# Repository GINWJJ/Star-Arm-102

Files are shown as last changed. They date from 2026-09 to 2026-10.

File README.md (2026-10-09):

<h1 align="center">🦾 Star Arm 102</h1>

<p align="center">
  <strong>Open-Source 6+1 DOF Robot Arm for LeRobot</strong><br>
  Teleoperate. Learn from demonstrations. Run your first AI task.
</p>

<p align="center">
  
  
  
  
  
</p>

<p align="center">
  
  
</p>

<p align="center">
  <a href="https://fashionstar.com.hk/">🌐 Official Website</a> ·
  <a href="https://fashionstar.com.hk/robot-arm/star-arm-102">🔭 Series Overview</a> ·
  <a href="#where-to-buy">🛒 Where to Buy</a> ·
  <a href="https://fashionstar.com.hk/support/">💬 Support</a>
</p>

<p align="center">
  <a href="https://fashionstar.com.hk/store/collections/robot-arm/star-arm-102/">
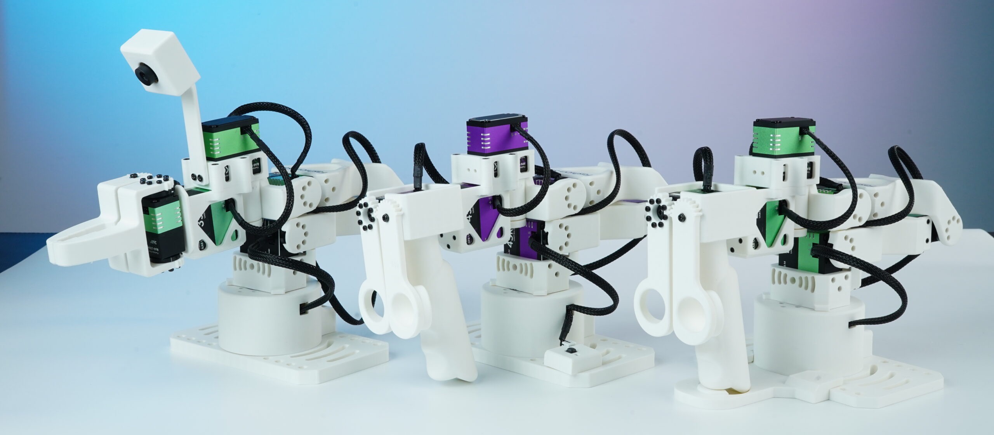
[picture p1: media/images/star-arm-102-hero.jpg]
Star Arm 102 robot arm
    
  </a>
</p>

## 📑 Contents

- [📖 Introduction](#introduction)
- [🛒 Where to Buy](#where-to-buy)
- [🚀 Get Started](docs/getting-started.md)
- [🌐 Cross-Brand Follower Compatibility](#cross-brand-pairings)
- [🎮 Connect Your Leader to a Virtual Follower](#web-controller)
- [🤖 Run Your First AI Task](#run-your-first-ai-task)
- [⚙️ Hardware Resources](hardware/)
- [🤗 LeRobot](lerobot/README.md)
- [💬 Natural Language Control](integrations/butterfly/README.md)
- [🦾 ROS 2 Humble Applications](ros2-humble/README.md)
- [🐍 Python SDK](python-sdk/README.md)
- [🧰 Control & Configuration Tools](tools/README.md)

[🛠️ Repository structure](#repository-structure) · [🔗 Related Projects](#related-projects)

---

## 📖 Introduction

Star Arm 102 is an open-source robot arm platform developed by **[Fashion Star](https://fashionstar.com.hk/)** for teleoperation, demonstration collection, and LeRobot learning workflows.

- **6+1 DoF, more wrist flexibility** — Six arm joints plus gripper control give you flexible wrist movement and versatile end-effector orientations.
- **Pieper-compliant kinematics** — Three consecutive parallel joint axes enable analytical inverse kinematics.
- **420 mm reach** — Across the LD, HD, and FL models for tabletop manipulation setups.
- **500g working payload** — The 102-FL follower features two high-torque brushless bus servo joints for task execution.
- **Two leader options** — Choose the lightweight 102-LD for free hand-guided teaching, or the pose-holding 102-HD with high-torque coreless bus servos for stable demonstrations.
- **Open-source resources** — STEP models, 3D-printing projects, BOMs, URDF robot descriptions, and control code for learning, building, and customization.
- **Teach by hand. Feel the load.** — Use ROS 2 for hand-guided teaching and feel changes in a supported follower's load through the 102-HD leader.
- **Pretrained ACT task** — Run the supplied block-placement policy on 102-FL without retraining, after completing the specified environment, calibration, and two-camera setup.

## 🔧 Specifications

| Specification | Star Arm 102-LD | Star Arm 102-HD | Star Arm 102-FL |
| --- | --- | --- | --- |
| Arm type | Leader Arm | Pose-holding Leader Arm | Follower Arm |
| Power | 12V@3A | 12V@5A | 12V@8A |
| Reach | 420mm | 420mm | 420mm |
| DoF | 6+1 | 6+1 | 6+1 |
| Payload | — | — | 500g (70% reach recommended) |
| Repeatability / Encoder | 12-bit magnetic encoder | 12-bit magnetic encoder | 2mm |
| Joint Motion Range | Joint 1: ±110°<br>Joint 2: 0°–180°<br>Joint 3: 0°–270°<br>Joint 4: ±90°<br>Joint 5: ±65°<br>Joint 6: ±150°<br>Handle: 0°–90° | Joint 1: ±110°<br>Joint 2: 0°–180°<br>Joint 3: 0°–270°<br>Joint 4: ±90°<br>Joint 5: ±65°<br>Joint 6: ±150°<br>Handle: 0°–90° | Joint 1: ±110°<br>Joint 2: 0°–180°<br>Joint 3: 0°–270°<br>Joint 4: ±90°<br>Joint 5: ±65°<br>Joint 6: ±150°<br>Gripper: 0°–90° |
| Servos | RA8-U01H-M × 4<br>RA8-U02H-M × 1<br>RA8-U03H-M × 2 | RP8-U45H-M × 4<br>RP8-U45H-M-C029 × 1<br>RP8-U45H-M-C028 × 2 | RA8-U35H-M × 3<br>RX8-U50H-M × 2<br>RA8-U27H-M-C005 × 1<br>RA8-U35H-M-C047 × 1 |
| Arm weight | 764g | 934g | 865g |
| Communication | UART / UC-01 | UART / UC-01 | UART / UC-01 |
| Operating Temperature | 0–40°C | 0–40°C | 0–40°C |

## 🛒 Where to Buy

Choose your [Star Arm 102](https://fashionstar.com.hk/store/collections/robot-arm/star-arm-102/) as a **fully assembled arm** to get started sooner, or a **DIY kit** to build it yourself. **In-stock options, ready to ship.** Select your model and configuration on the product page for current availability.

**International store:**

| Product | Shop | Product overview |
| :---: | --- | --- |
| <a href="https://fashionstar.com.hk/store/product/star-arm-102-ld/">Star Arm 102-LD</a> | **[Shop&nbsp;102&#8209;LD&nbsp;→](https://fashionstar.com.hk/store/product/star-arm-102-ld/)** | **Lightweight leader arm** for hand-guided teaching, teleoperation, and demonstration collection; torque-disabled joints move freely |
| <a href="https://fashionstar.com.hk/store/product/star-arm-102-hd/">Star Arm 102-HD</a> | **[Shop&nbsp;102&#8209;HD&nbsp;→](https://fashionstar.com.hk/store/product/star-arm-102-hd/)** | **Pose-holding leader arm** with high-torque coreless bus servos, for stable demonstrations and extended data collection |
| <a href="https://fashionstar.com.hk/store/product/star-arm-102-fl/">Star Arm 102-FL</a> | **[Shop&nbsp;102&#8209;FL&nbsp;→](https://fashionstar.com.hk/store/product/star-arm-102-fl/)** | **Follower arm** for teleoperation and policy execution; two high-torque brushless bus servo joints, with a specified 500g working payload |

**Chinese purchase channel:** [Taobao](https://item.taobao.com/item.htm?id=1045277992605&skuId=6239416958433). Select the required model and kit option on the listing.

## 🌐 One Leader, Multiple Robot Platforms

Have a third-party follower? Explore Star Arm 102-LD / HD pairing resources by follower model, then choose the matching Python or LeRobot path.

<!-- reBot image: transparent image extracted with empty alpha margins trimmed from page 1 of Seeed Studio’s product sheet, hosted at https://akizukidenshi.com/goodsaffix/reBot_Arm_B601_DM_Physical_AI_Robotics_Arm.pdf -->
<table>
  <tr>
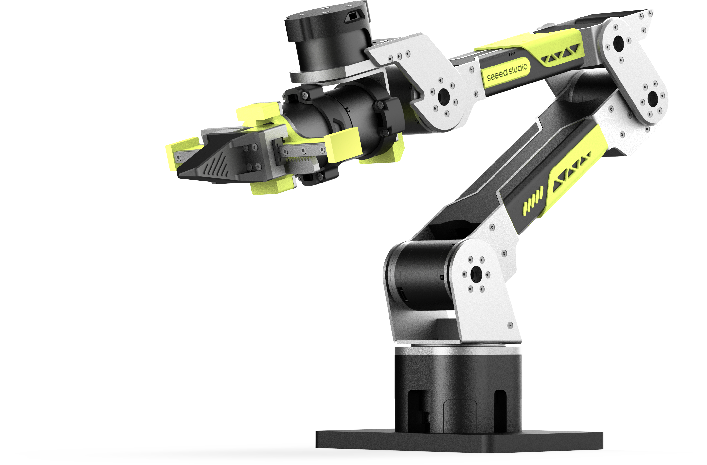
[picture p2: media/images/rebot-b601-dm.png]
Seeed reBot B601-DM
    <td align="center" width="25%"></td>
    <td align="center" width="25%"><a href="integrations/yam/README.md">I2RT YAM</a></td>
    <td align="center" width="25%"><a href="integrations/galaxea-a1/README.md">Galaxea A1</a></td>
    <td align="center" width="25%"><a href="integrations/lumos-touch/README.md">Lumos Touch R1</a></td>
  </tr>
  <tr>
    <td align="center"><a href="integrations/seeed-rebot/README.md"><strong>Seeed reBot<br>B601-DM &amp; B601-RS →</strong></a></td>
    <td align="center"><a href="integrations/yam/README.md"><strong>YAM →</strong></a></td>
    <td align="center"><a href="integrations/galaxea-a1/README.md"><strong>Galaxea A1 →</strong></a></td>
    <td align="center"><a href="integrations/lumos-touch/README.md"><strong>Lumos Touch →</strong></a></td>
  </tr>
</table>

**[Cross-Brand Compatibility and Evidence →](integrations/compatibility.md)**

## 🎮 Connect Your Leader to a Virtual Follower

Start with your Star Arm 102 leader and a virtual follower in the web controller—no physical follower needed for this first experience.

- Get familiar with teleoperation and prepare your setup before connecting a physical follower.
- Follow the Wiki guide for supported leader models, connection steps, and calibration instructions.

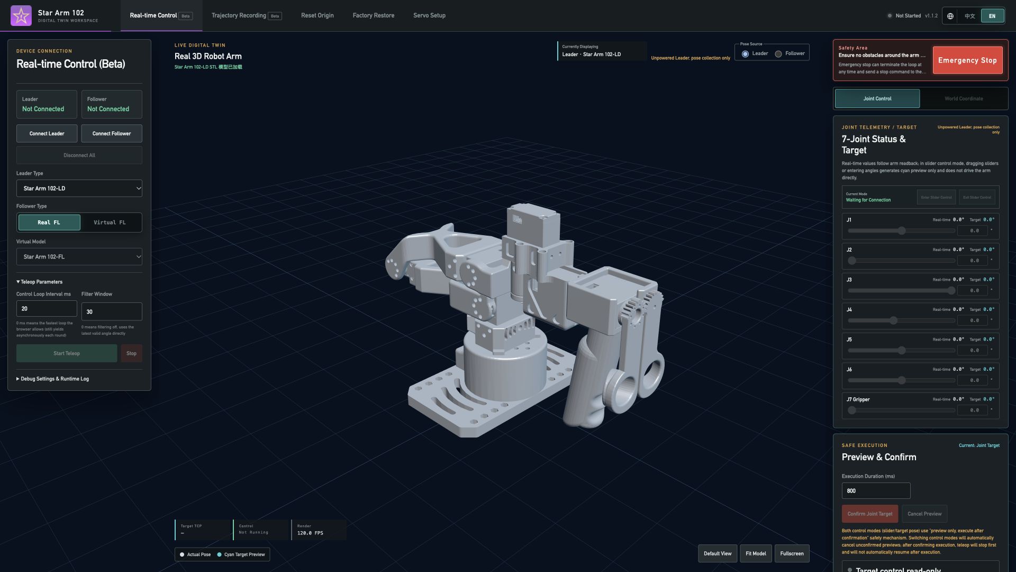
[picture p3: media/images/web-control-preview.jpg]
Star Arm 102 web control interface preview (https://fashionstar.com.hk/wiki/software/robot-arm/web-config-tool/)


**[Connect Your Leader →](https://fashionstar.com.hk/wiki/software/robot-arm/web-config-tool/)**

*Interface preview with no hardware connected. Tool versions, downloads, and detailed instructions are maintained in the Wiki.*

## 🤖 Run Your First AI Task

Watch Star Arm 102-FL pick up and place a block using our pretrained ACT model. Then try the same task on your own 102-FL—**no retraining required**.

<p align="center">
  <a href="https://github.com/user-attachments/assets/6774384d-f437-4aa9-a364-cd66eba965f7">
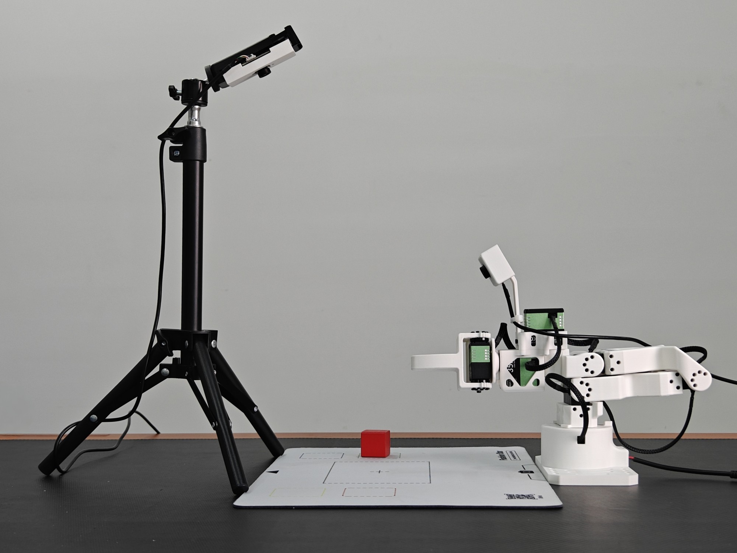
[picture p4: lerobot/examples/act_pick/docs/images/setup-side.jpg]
Side view of the Star Arm 102 ACT workspace — watch the block-placement demo
    
  </a><br>
  <a href="https://github.com/user-attachments/assets/6774384d-f437-4aa9-a364-cd66eba965f7"><strong>▶ Watch the ACT block-placement demo</strong></a>
</p>

**[Run the Demo on Your Arm →](lerobot/examples/act_pick/README.md)**

The guide walks you through the required hardware, two-camera setup, calibration, and workspace preparation.

## 🎮 Teach by Hand. Feel the Load.

Explore two ways to interact with your arm through ROS 2:

- **Hand-Guided Teaching** — Guide the arm by hand to demonstrate motion through ROS 2.
- **Force Feedback on 102-HD** — Feel changes in a supported follower's load as changes in resistance at the HD leader, bringing a sense of the remote arm's effort to your hand.

**[Explore ROS 2 Capabilities →](ros2-humble/README.md)**

*Feature-specific setup guides, supported arm combinations, and validation records are being prepared.*

## 🛠️ Repository structure

```text
Star-Arm-102/
├── README.md
├── README.zh.md
├── hardware/
│   ├── 102-ld/                               BOM in each model README; LD layout expanded below
│   │   ├── step/
│   │   │   ├── assembly/
│   │   │   └── parts/
│   │   ├── printing/
│   │   │   ├── stl/
│   │   │   └── 3mf/
│   │   ├── drawings/
│   │   ├── images/
│   │   ├── assembly-guide/
│   │   └── robot-description/
│   ├── 102-hd/
│   ├── 102-fl/
│   ├── camera-module/
│   └── flexible-gripper/
├── integrations/
│   ├── seeed-rebot/
│   ├── yam/
│   ├── galaxea-a1/
│   ├── lumos-touch/
│   └── butterfly/                            Natural-language control application
├── lerobot/
│   ├── examples/act_pick/
│   ├── lerobot-robot-stararm102/
│   ├── lerobot-teleoperator-stararm102/
│   └── lerobot-stararm102/
├── python-sdk/
├── ros2-humble/
│   └── src/
├── tools/                                    Web control and servo configuration tools
├── docs/                                     Getting started, wiring, and troubleshooting
├── media/
├── scripts/
├── tests/
├── .github/
├── AGENTS.md
├── CONTRIBUTING.md
├── CHANGELOG.md
└── LICENSE.md
```

## 🌐 Related projects

- [Fashion Star UART/RS-485 Bus Servo SDK](https://github.com/servodevelop/servo-uart-rs485-sdk)
- [Fashion Star CAN Bus Servo SDK](https://github.com/servodevelop/servo-canbus-sdk)
- [PiPER-Mate](https://github.com/servodevelop/piper-mate) — A compact leader arm with the AgileX PiPER joint layout, for teleoperating PiPER followers and collecting training data.
- [StarAI Arm](https://github.com/servodevelop/lerobot-starai) — An ALOHA-style arm series pairing a Violin leader with Viola or Cello followers for LeRobot imitation learning and data collection.

Software directories and model release URLs remain available. English is the default entry; existing English and Chinese READMEs maintain matching sections, images, commands, and status. English-only detailed documents remain accessible through their links. The [historical Chinese homepage](README.legacy.zh.md) is retained for reference, not as the current operating guide.

[Changes](CHANGELOG.md) · [Contributing](CONTRIBUTING.md) · [License scope](LICENSE.md)

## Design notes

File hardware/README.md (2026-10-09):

# Star Arm 102 Specifications & Hardware Resources

[← Home](../README.md)　|　<sub>**English** / [简体中文](README.zh.md)</sub>

**On this page:**

- [🔧 Specifications](#product-specifications)
- [📂 Directory Structure](#directory-structure)

Explore your model: **[102-LD](102-ld/)** · **[102-HD](102-hd/)** · **[102-FL](102-fl/)**.

Accessories: **[Camera Module](camera-module/)** · **[Flexible Gripper](flexible-gripper/)**.

## Specifications

| Specification | Star Arm 102-LD | Star Arm 102-HD | Star Arm 102-FL |
| --- | --- | --- | --- |
| Arm type | Leader Arm | Pose-holding Leader Arm | Follower Arm |
| Power | 12V@3A | 12V@5A | 12V@8A |
| Reach | 420mm | 420mm | 420mm |
| DoF | 6+1 | 6+1 | 6+1 |
| Payload | — | — | 500g (70% reach recommended) |
| Repeatability / Encoder | 12-bit magnetic encoder | 12-bit magnetic encoder | 2mm |
| Joint Motion Range | Joint 1: ±110°<br>Joint 2: 0°–180°<br>Joint 3: 0°–270°<br>Joint 4: ±90°<br>Joint 5: ±65°<br>Joint 6: ±150°<br>Handle: 0°–90° | Joint 1: ±110°<br>Joint 2: 0°–180°<br>Joint 3: 0°–270°<br>Joint 4: ±90°<br>Joint 5: ±65°<br>Joint 6: ±150°<br>Handle: 0°–90° | Joint 1: ±110°<br>Joint 2: 0°–180°<br>Joint 3: 0°–270°<br>Joint 4: ±90°<br>Joint 5: ±65°<br>Joint 6: ±150°<br>Gripper: 0°–90° |
| Servos | RA8-U01H-M × 4<br>RA8-U02H-M × 1<br>RA8-U03H-M × 2 | RP8-U45H-M × 4<br>RP8-U45H-M-C029 × 1<br>RP8-U45H-M-C028 × 2 | RA8-U35H-M × 3<br>RX8-U50H-M × 2<br>RA8-U27H-M-C005 × 1<br>RA8-U35H-M-C047 × 1 |
| Arm weight | 764g | 934g | 865g |
| Communication | UART / UC-01 | UART / UC-01 | UART / UC-01 |
| Operating Temperature | 0–40°C | 0–40°C | 0–40°C |

## Directory structure

The LD layout is expanded below. HD and FL use the same resource categories, with model-specific files and inline BOMs. Individual files are omitted.

```text
hardware/
├── README.md
├── README.zh.md
├── 102-ld/
│   ├── README.md
│   ├── README.zh.md
│   ├── step/
│   │   ├── assembly/
│   │   └── parts/
│   ├── printing/
│   │   ├── stl/
│   │   └── 3mf/
│   ├── drawings/
│   ├── images/
│   ├── assembly-guide/
│   │   └── images/
│   └── robot-description/
│       ├── stararm102_ld_hd_description/
│       └── star-arm-102-ld-hd-urdf.zip
├── 102-hd/
├── 102-fl/
├── camera-module/
└── flexible-gripper/
```

`step/assembly/` contains CAD assemblies; `assembly-guide/` is for customer assembly instructions. Each model provides its ROS 1 source package and complete ZIP in its own robot-description directory: [LD](102-ld/robot-description/), [HD](102-hd/robot-description/), [FL](102-fl/robot-description/). LD and HD contain the same model.

## Licensing

Hardware licensing remains unresolved; see [license scope](../LICENSE.md). No new license is granted by copying or renaming files.

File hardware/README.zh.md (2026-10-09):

# Star Arm 102 规格与硬件资源

[← 首页](../README.zh.md)　|　<sub>[English](README.md) / **简体中文**</sub>

**本页导航：**

- [🔧 规格](#product-specifications)
- [📂 目录结构](#directory-structure)

按型号查看详情：**[102-LD](102-ld/)** · **[102-HD](102-hd/)** · **[102-FL](102-fl/)**。

配件：**[摄像头模组](camera-module/)** · **[柔性夹爪](flexible-gripper/)**。

## 规格

| 规格 | Star Arm 102-LD | Star Arm 102-HD | Star Arm 102-FL |
| --- | --- | --- | --- |
| 产品类型 | 示教主臂（Leader Arm） | 姿态保持主臂（Leader Arm） | 执行从臂（Follower Arm） |
| 电源规格 | 12V@3A | 12V@5A | 12V@8A |
| 臂展 | 420mm | 420mm | 420mm |
| 自由度 | 6+1 | 6+1 | 6+1 |
| 负载 | — | — | 500g（建议在 70% 臂展处使用） |
| 重复定位精度／编码器 | 12-bit 磁编码器 | 12-bit 磁编码器 | 2mm |
| 关节运动范围 | 关节 1: ±110°<br>关节 2: 0°–180°<br>关节 3: 0°–270°<br>关节 4: ±90°<br>关节 5: ±65°<br>关节 6: ±150°<br>手柄: 0°–90° | 关节 1: ±110°<br>关节 2: 0°–180°<br>关节 3: 0°–270°<br>关节 4: ±90°<br>关节 5: ±65°<br>关节 6: ±150°<br>手柄: 0°–90° | 关节 1: ±110°<br>关节 2: 0°–180°<br>关节 3: 0°–270°<br>关节 4: ±90°<br>关节 5: ±65°<br>关节 6: ±150°<br>夹爪: 0°–90° |
| 舵机配置 | RA8-U01H-M × 4<br>RA8-U02H-M × 1<br>RA8-U03H-M × 2 | RP8-U45H-M × 4<br>RP8-U45H-M-C029 × 1<br>RP8-U45H-M-C028 × 2 | RA8-U35H-M × 3<br>RX8-U50H-M × 2<br>RA8-U27H-M-C005 × 1<br>RA8-U35H-M-C047 × 1 |
| 本机重量 | 764g | 934g | 865g |
| 通信方式 | UART / UC-01 | UART / UC-01 | UART / UC-01 |
| 工作温度 | 0–40°C | 0–40°C | 0–40°C |

## 目录结构

下方展开 LD 的目录。HD 和 FL 使用相同资源分类，各自提供型号对应文件和页内 BOM。省略具体文件。

```text
hardware/
├── README.md
├── README.zh.md
├── 102-ld/
│   ├── README.md
│   ├── README.zh.md
│   ├── step/
│   │   ├── assembly/
│   │   └── parts/
│   ├── printing/
│   │   ├── stl/
│   │   └── 3mf/
│   ├── drawings/
│   ├── images/
│   ├── assembly-guide/
│   │   └── images/
│   └── robot-description/
│       ├── stararm102_ld_hd_description/
│       └── star-arm-102-ld-hd-urdf.zip
├── 102-hd/
├── 102-fl/
├── camera-module/
└── flexible-gripper/
```

`step/assembly/` 存放 CAD 装配模型；`assembly-guide/` 用于客户装配说明。每个型号均在自身的 robot-description 目录提供 ROS 1 源码与完整 ZIP：[LD](102-ld/robot-description/)、[HD](102-hd/robot-description/)、[FL](102-fl/robot-description/)。LD 与 HD 包含相同模型。

## 许可

硬件许可仍待明确，见 [许可范围](../LICENSE.md)。复制或重命名文件不授予新的许可。

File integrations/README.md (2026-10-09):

# Integrations: Follower Pairings & Partner Applications

[← Home](../README.md)　|　<sub>**English**</sub>

**On this page:**

- [🌐 Cross-brand follower pairings](#page-section-1)
- [🧭 Choose a workflow](#page-section-2)
- [🤝 Partner applications](#page-section-3)
- [🛠️ How these resources are maintained](#page-section-4)

Find [cross-brand follower pairings](#cross-brand-follower-pairings) or [partner applications](#partner-applications).

## Cross-brand follower pairings

Use this directory to explore Star Arm 102-LD / HD leader pairings with third-party followers. Start with your follower model, then choose its Python or LeRobot workflow.

| Your follower | Pairing guide | Current documentation status |
| --- | --- | --- |
| Galaxea A1 | [A1 pairing](galaxea-a1/README.md) | Pairing-specific code, setup instructions, and test records pending |
| Lumos Touch | [Touch pairing](lumos-touch/README.md) | Pairing-specific code, setup instructions, and test records pending |
| YAM — exact model to be confirmed | [YAM pairing](yam/README.md) | Model identification and pairing guide pending |
| Seeed reBot B601 | [B601 pairing](seeed-rebot/README.md) | Upstream LeRobot guide available for B601-DM and B601-RS; verify exact leader and variant |

These entries identify customer pairing needs. Listing a model does not establish tested support for both LD and HD, or for every software workflow. See the [capability and evidence matrix](compatibility.md) before choosing hardware or installing software.

## Choose a workflow

- **Python:** direct teleoperation requires a driver and mapping for the specific follower. The current [Python SDK examples](../python-sdk/README.md) target Star Arm 102-FL.
- **LeRobot:** use the pairing's documented follower plugin and leader interface. The [LeRobot directory](../lerobot/README.md) holds the existing Star Arm integrations; they are not universal follower drivers.
- **Wiki and tools:** [Control tools](../tools/README.md) link to the Wiki. Pairing-specific courses will be linked from each model guide when available.

Start with [common preparation](common-setup.md), then your model guide. For an all-Star Arm setup, use [getting started](../docs/getting-started.md).

## Partner applications

| Application | Purpose | Guide and validation status |
| --- | --- | --- |
| Butterfly Community Robot Arm | Natural-language task control and partner-maintained robot application | [Overview](butterfly/README.md) · [Compatibility](butterfly/compatibility.md) · [Setup](butterfly/setup.md) · [Troubleshooting](butterfly/troubleshooting.md) |

Partner applications are a separate category from leader–follower pairings. Check each application's model and environment requirements before use. See the [Chinese Butterfly guide](butterfly/README.zh-CN.md) for the complete Chinese version.

## How these resources are maintained

This directory owns pairing requirements, capability status, and navigation. Python implementations remain in `python-sdk/`, and LeRobot plugins remain in `lerobot/` or their linked upstream repositories. Each command sequence should have one authoritative location. Detailed tutorials and videos belong in the Wiki; tool binaries and vendor SDK copies are not mirrored here.

[Home](../README.md) · [Leader hardware](../hardware/README.md) · [Software environments](../docs/compatibility.md)

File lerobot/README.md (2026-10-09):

# LeRobot on Star Arm 102

[← Home](../README.md)　|　<sub>**English**</sub>

**On this page:**

- [📦 Release-compatible environment](#page-section-1)
- [🎯 Calibrate the LD leader and FL follower](#page-section-2)
- [🎮 First teleoperation](#page-section-3)
- [🚀 Next steps](#page-section-4)

[Get started](../docs/getting-started.md) · [Compatibility](../docs/compatibility.md) · [Pretrained ACT model](examples/act_pick/README.md)

For Galaxea A1, Lumos Touch, YAM, or Seeed reBot, first check the [pairing guide and capability status](../integrations/README.md). The FL plugins below do not establish support for third-party followers.

Choose one integration before installing. Both generations use the same leader package name, so keep them in **separate Python environments**.

| Your goal | Integration | Next step |
| --- | --- | --- |
| Try the released ACT block-placement model | Released 0.0.1 plugins, `Motor_0`…`Motor_5`, `gripper` | [ACT installation and inference](examples/act_pick/inference.md) |
| LD → FL teleoperation with the release-compatible plugins | `lerobot_robot_stararm102` + `lerobot_teleoperator_stararm102` | Continue below |
| HD button support, or new work using named joints | Refactored `stararm102_hd` + `stararm102_fl` | [HD/FL integration](lerobot-stararm102/README.md) |
| A Seeed reBot follower | Upstream B601 integration | [reBot setup](../integrations/seeed-rebot/README.md) |

The old plugin pair does not expose the refactored HD button configuration. A pretrained policy is tied to its joint names, calibration representation, and cameras; switching plugins is not a transparent upgrade.

## Release-compatible environment

Use Ubuntu 22.04, Python 3.10, and the versioned [ACT environment instructions](examples/act_pick/inference.md#install-the-environment), even if you only need teleoperation. For source development, the corresponding packages remain in [lerobot-robot-stararm102](lerobot-robot-stararm102/README.md) and [lerobot-teleoperator-stararm102](lerobot-teleoperator-stararm102/README.md).

Confirm communication first with the [Python communication check](../python-sdk/README.md#check-communication-without-commanding-motion). Close it before opening the ports in LeRobot.

## Calibrate the LD leader and FL follower

Secure the bases, support the arms while torque is disabled, and clear their motion areas. Replace the example ports with the ones you identified. Device IDs below are calibration names, not servo bus IDs; reuse them in later commands.

```bash
lerobot-calibrate \
  --teleop.type=lerobot_teleoperator_stararm102 \
  --teleop.port=/dev/ttyUSB0 \
  --teleop.id=customer_stararm102_leader

lerobot-calibrate \
  --robot.type=lerobot_robot_stararm102 \
  --robot.port=/dev/ttyUSB1 \
  --robot.id=customer_stararm102_follower
```

Follow the terminal prompts to record each joint's available range, including the gripper; do not force mechanical stops. If a calibration exists, the prompt lets you reuse it or type `c` to recalibrate. Keep each calibration with the same physical arm and plugin generation.

**Success:** each command reports that calibration was saved, and all seven joints have meaningful recorded ranges. A connected arm alone does not prove calibration is correct.

## First teleoperation

```bash
lerobot-teleoperate \
  --teleop.type=lerobot_teleoperator_stararm102 \
  --teleop.port=/dev/ttyUSB0 \
  --teleop.id=customer_stararm102_leader \
  --robot.type=lerobot_robot_stararm102 \
  --robot.port=/dev/ttyUSB1 \
  --robot.id=customer_stararm102_follower
```

Move one joint slowly through a small range, then check the gripper. Stop if direction or alignment is wrong. `Ctrl+C` exits the process; it is not a hardware emergency stop. See [stopping guidance](../docs/hardware-setup.md#reference-pose-and-stopping).

## Next steps

- [Run the supplied ACT policy](examples/act_pick/inference.md).
- [Plan your own ACT training task](examples/act_pick/training.md).
- [Troubleshoot installation, calibration, and cameras](../docs/troubleshooting.md).
- Older extended tutorials remain as [Chinese supplementary material](stararm102.md) and an [archived English tutorial](stararm102_en.md). Use this page for the current entry path.

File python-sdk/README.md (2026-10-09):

# Python control: first connection and teleoperation

[← Home](../README.md)　|　<sub>**English**</sub>

**On this page:**

- [🛠️ Install](#page-section-1)
- [🔌 Check communication without commanding motion](#page-section-2)
- [🎮 Start teleoperation](#page-section-3)
- [❓ Help](#page-section-4)

[Get started](../docs/getting-started.md) · [Detailed behavior](PYTHON_SDK_GUIDE.md) · [中文补充](PYTHON_SDK_GUIDE.zh.md)

Use this path for direct **102-LD or 102-HD → 102-FL** teleoperation, without ROS or LeRobot. A single FL can run the communication check. For Galaxea A1, Lumos Touch, YAM, or Seeed reBot, start with the [cross-brand pairing directory](../integrations/README.md). These examples are FL-specific; a third-party follower needs its own driver and mapping.

## Install

The commands below target Ubuntu 22.04 and Python 3.10. From a terminal:

```bash
sudo apt install python3-venv git
git clone https://github.com/servodevelop/Star-Arm-102.git
cd Star-Arm-102
python3 -m venv .venv-python
source .venv-python/bin/activate
python -m pip install -r python-sdk/requirements.txt
```

If you already cloned the repository, enter that checkout instead. Commands below run from the repository root. Reactivate `.venv-python` in a new terminal.

Read [power, wiring, and serial-port identification](../docs/hardware-setup.md) before continuing. Replace the example ports with your actual devices.

## Check communication without commanding motion

```bash
python python-sdk/check_connection.py --port /dev/ttyUSB0
python python-sdk/check_connection.py --port /dev/ttyUSB1
```

Each arm should report `ID 0: OK` through `ID 6: OK`. The check only pings devices; it does not unlock joints, reset origins, or send target angles. This verifies communication, not calibration or mechanical readiness. Stop here if any ID does not respond.

For an HD button board at ID 7:

```bash
python python-sdk/check_connection.py --port /dev/ttyUSB0 --ids 7
```

## Start teleoperation

Secure both bases, clear the motion area, and place both arms in their matching physical reference poses. See [reference pose and stopping](../docs/hardware-setup.md#reference-pose-and-stopping). This script unlocks joints and resets multi-turn counts on connection; it can command the follower immediately. It does not load LeRobot calibration.

**LD leader:**

```bash
python python-sdk/stararm102_ro.py \
  --leader-type 102LD \
  --leader-port /dev/ttyUSB0 \
  --follower-port /dev/ttyUSB1
```

**HD leader with its button board:**

```bash
python python-sdk/stararm102_ro.py \
  --leader-type 102HD \
  --leader-port /dev/ttyUSB0 \
  --follower-port /dev/ttyUSB1
```

HD mode enables the board at ID 7. If your HD configuration intentionally has no board, append `--button_disable`; the button function will be unavailable. See [button behavior](PYTHON_SDK_GUIDE.md#hd-button-behavior).

Move one leader joint slowly through a small range. Check that the corresponding follower joint moves in the expected direction; then check the gripper. Stop if alignment or direction is wrong. The terminal prints `Loop frequency: ... Hz`; this is a measured loop rate, not a guaranteed control specification.

Press `Ctrl+C` to exit. This is not a hardware emergency stop and does not guarantee the arm releases torque or cancels motion. Use the hardware power-off procedure for unexpected movement.

**Success:** all IDs respond and the FL follows small leader movements correctly. Continue to [LeRobot](../lerobot/README.md) or [the pretrained ACT example](../lerobot/examples/act_pick/README.md).

## Help

```bash
python python-sdk/stararm102_ro.py --help
python python-sdk/check_connection.py --help
```

See [troubleshooting](../docs/troubleshooting.md) if connection or movement is incorrect. Keep `set-param.py`, `test.py`, and `stararm102_ro_hover.py` for developer use after reviewing their source; they are not first-use checks.

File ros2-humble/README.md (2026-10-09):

# Star Arm 102 with ROS 2 Humble

[← Home](../README.md)　|　<sub>**English** / [简体中文](README.zh.md)</sub>

**On this page:**

- [🛠️ Install and build](#page-section-1)
- [🎮 Try the virtual arm first](#page-section-2)
- [🔌 Connect a real FL](#page-section-3)
- [💡 Other examples](#page-section-4)
- [🌐 Gazebo](#page-section-5)
- [📂 Workspace map](#page-section-6)

[Get started](../docs/getting-started.md) · [Troubleshooting](../docs/troubleshooting.md)

This workspace contains the FL driver, URDF, MoveIt configuration, Gazebo simulation, and teaching examples. Python teleoperation and the ACT demo do not require ROS.

## Install and build

Use **Ubuntu 22.04 + ROS 2 Humble**, as in the existing project guide. Start a terminal outside your LeRobot/Conda environment. Follow the [ROS 2 Humble Ubuntu installation guide](https://docs.ros.org/en/humble/Installation/Ubuntu-Install-Debs.html), then:

```bash
sudo apt update
sudo apt install ros-humble-moveit python3-colcon-common-extensions python3-rosdep python3-pip python3-serial
python3 -m pip install --user fashionstar-uart-sdk==1.3.12
source /opt/ros/humble/setup.bash
git clone https://github.com/servodevelop/Star-Arm-102.git
cd Star-Arm-102/ros2-humble
```

If already cloned, enter that workspace instead. Initialize rosdep once if it has not been initialized (`sudo rosdep init`), then:

```bash
rosdep update
rosdep install --from-paths src --ignore-src -r -y
colcon build
source install/setup.bash
```

In each new terminal, source `/opt/ros/humble/setup.bash` and this workspace's `install/setup.bash`. This documentation update has not been built on a ROS host; see [validation status](../docs/validation.md).

## Try the virtual arm first

```bash
ros2 launch stararm102_moveit_config demo.launch.py
```

In RViz, use the Motion Planning panel to select a planning group, move the interactive marker, and choose **Plan**, then **Execute**. This launch is the virtual-arm path; do not start the hardware driver for this check.

**Success:** the model appears and a planned trajectory executes in the virtual scene.

## Connect a real FL

Complete [hardware setup and port identification](../docs/hardware-setup.md). Close other programs using the serial port.

The driver currently sets its port in [robo_driver.py](src/robo_driver/robo_driver/robo_driver.py): change `SERVO_PORT_NAME` to the FL port before building; its default is `/dev/ttyUSB0`, baud rate `1000000`. Rebuild and source the workspace after editing. Do not assume the port used in a LeRobot example is the driver's default.

**Launching the driver can move the arm to its zero position.** Secure the base, check the physical reference pose, clear the work area, and keep servo power control accessible. `Ctrl+C` is not a hardware emergency stop.

Terminal 1:

```bash
ros2 launch stararm102_moveit_config driver.launch.py
```

Terminal 2:

```bash
ros2 launch stararm102_moveit_config actual_robot_demo.launch.py
```

Start with small, reviewed plans. Confirm joint feedback and direction before executing a larger trajectory. Do not run the driver and a Python/LeRobot controller on the same serial port at the same time.

## Other examples

These examples can command motion when a real driver is running. Review targets before launching them.

| Purpose | Command |
| --- | --- |
| End-effector pose read/write | `ros2 launch stararm102_moveit_config moveit_write_read.launch.py` |
| Publish pose targets | `ros2 run arm_moveit_write topic_publisher` |
| Teaching with joints unlocked | `ros2 run robo_driver driver --ros-args -p lock:=disable` |
| Record a teaching trajectory | `ros2 run ros2_bag_recorder bag_recorder --ros-args -p dataset:=star/record-test` |
| Replay a saved trajectory | `ros2 bag play ./star/record-test` |

Support the arm when unlocking. For recording, press Enter to start and again to finish. Choose a new dataset path for each recording. To replay on hardware, stop the teaching driver and start the normal driver only after preparing the arm; playing a bag can execute the recorded motion.

## Gazebo

Use a separate simulation session with the real driver stopped:

```bash
sudo apt install gazebo ros-humble-gazebo-ros-pkgs ros-humble-gazebo-ros
ros2 launch stararm102_gazebo stararm102_gazebo.launch.py
```

In another sourced terminal:

```bash
ros2 launch stararm102_moveit_config gazebo_demo.launch.py
```

## Workspace map

| Package | Purpose |
| --- | --- |
| `robo_driver` / `robo_interfaces` | Servo communication and interfaces |
| `stararm102_description` | Robot geometry and URDF |
| `stararm102_controller` | Controller integration |
| `stararm102_moveit_config` | Motion planning launches/configuration |
| `stararm102_gazebo` | Simulation |
| `arm_moveit_read`, `arm_moveit_write`, `arm_read_pose` | Pose examples |
| `ros2_bag_recorder` | Teaching trajectory recording |

For serial access, use the [port permissions guide](../docs/hardware-setup.md#identify-serial-ports). For an RViz scaling issue, try `export QT_AUTO_SCREEN_SCALE_FACTOR=0` before reopening RViz. If a build fails, include the failed package and complete error in a [support issue](https://github.com/servodevelop/Star-Arm-102/issues/new/choose).

[Historical Chinese material (not the current operating guide)](legacy-guide.zh.md)

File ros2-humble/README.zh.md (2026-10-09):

# Star Arm 102 与 ROS 2 Humble

[← 首页](../README.zh.md)　|　<sub>[English](README.md) / **简体中文**</sub>

**本页导航：**

- [🛠️ 安装与构建](#page-section-1)
- [🎮 先体验虚拟机械臂](#page-section-2)
- [🔌 连接真实 FL](#page-section-3)
- [💡 其他示例](#page-section-4)
- [🌐 Gazebo](#page-section-5)
- [📂 工作区结构](#page-section-6)

[开始使用](../docs/getting-started.md) · [排错](../docs/troubleshooting.md)

本工作区包含 FL 驱动、URDF、MoveIt 配置、Gazebo 仿真和示教示例。Python 遥操作和 ACT 演示无需 ROS。

## 安装与构建

使用现有项目指南指定的 **Ubuntu 22.04 + ROS 2 Humble**。在 LeRobot／Conda 环境之外启动终端，按照 [ROS 2 Humble Ubuntu 安装指南](https://docs.ros.org/en/humble/Installation/Ubuntu-Install-Debs.html) 安装，然后执行：

```bash
sudo apt update
sudo apt install ros-humble-moveit python3-colcon-common-extensions python3-rosdep python3-pip python3-serial
python3 -m pip install --user fashionstar-uart-sdk==1.3.12
source /opt/ros/humble/setup.bash
git clone https://github.com/servodevelop/Star-Arm-102.git
cd Star-Arm-102/ros2-humble
```

如果已经克隆仓库，直接进入工作区。若尚未初始化 rosdep，先执行一次 `sudo rosdep init`，然后：

```bash
rosdep update
rosdep install --from-paths src --ignore-src -r -y
colcon build
source install/setup.bash
```

每个新终端都需加载 `/opt/ros/humble/setup.bash` 和本工作区的 `install/setup.bash`。本次文档更新尚未在 ROS 主机上构建验证，见 [验证状态](../docs/validation.md)。

## 先体验虚拟机械臂

```bash
ros2 launch stararm102_moveit_config demo.launch.py
```

在 RViz 的 Motion Planning 面板中选择规划组，移动交互标记，先点击 **Plan**，再点击 **Execute**。这是虚拟机械臂启动路径；此项检查无需启动实物驱动。

**成功标志：**模型正常显示，规划轨迹能在虚拟场景中执行。

## 连接真实 FL

完成 [硬件配置与端口识别](../docs/hardware-setup.md)，关闭其他占用串口的程序。

当前驱动在 [robo_driver.py](src/robo_driver/robo_driver/robo_driver.py) 中设置端口：构建前将 `SERVO_PORT_NAME` 改为 FL 的实际端口；默认值为 `/dev/ttyUSB0`，波特率为 `1000000`。修改后重新构建并加载工作区环境。不要假定 LeRobot 示例中的端口就是此驱动的默认端口。

**启动驱动可能使机械臂移动到零位。** 请固定底座、核对实物参考姿态、清空工作区域，并确保可随时切断舵机电源。`Ctrl+C` 不是硬件急停。

终端 1：

```bash
ros2 launch stararm102_moveit_config driver.launch.py
```

终端 2：

```bash
ros2 launch stararm102_moveit_config actual_robot_demo.launch.py
```

从经过检查的小范围轨迹开始。执行较大轨迹前确认关节反馈与方向。不要让驱动和 Python／LeRobot 控制程序同时占用同一个串口。

## 其他示例

真实驱动运行时，这些示例可能下发运动指令。启动前请检查目标。

| 用途 | 命令 |
| --- | --- |
| 末端位姿读写 | `ros2 launch stararm102_moveit_config moveit_write_read.launch.py` |
| 发布位姿目标 | `ros2 run arm_moveit_write topic_publisher` |
| 关节解锁示教 | `ros2 run robo_driver driver --ros-args -p lock:=disable` |
| 记录示教轨迹 | `ros2 run ros2_bag_recorder bag_recorder --ros-args -p dataset:=star/record-test` |
| 回放已保存轨迹 | `ros2 bag play ./star/record-test` |

解锁时请托住机械臂。录制时按 Enter 开始，再按一次结束。每次录制使用新的数据集路径。真机回放前停止示教驱动，准备好机械臂后再启动正常驱动；播放 bag 可能执行已记录的动作。

## Gazebo

停止真实驱动，使用独立仿真会话：

```bash
sudo apt install gazebo ros-humble-gazebo-ros-pkgs ros-humble-gazebo-ros
ros2 launch stararm102_gazebo stararm102_gazebo.launch.py
```

在另一个已加载环境的终端中执行：

```bash
ros2 launch stararm102_moveit_config gazebo_demo.launch.py
```

## 工作区结构

| 功能包 | 用途 |
| --- | --- |
| `robo_driver` / `robo_interfaces` | 舵机通信和接口 |
| `stararm102_description` | 机器人几何模型和 URDF |
| `stararm102_controller` | 控制器集成 |
| `stararm102_moveit_config` | 运动规划启动文件及配置 |
| `stararm102_gazebo` | 仿真 |
| `arm_moveit_read`, `arm_moveit_write`, `arm_read_pose` | 位姿示例 |
| `ros2_bag_recorder` | 示教轨迹记录 |

串口访问权限见 [端口权限指南](../docs/hardware-setup.md#identify-serial-ports)。遇到 RViz 缩放问题时，可在重新打开前尝试 `export QT_AUTO_SCREEN_SCALE_FACTOR=0`。构建失败时，请在 [问题反馈](https://github.com/servodevelop/Star-Arm-102/issues/new/choose) 中提供失败的功能包及完整错误。

[历史中文资料（非当前操作指南）](legacy-guide.zh.md)

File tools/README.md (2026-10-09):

# Control & Configuration Tools

[← Home](../README.md)　|　<sub>**English**</sub>

**On this page:**

- [🧰 Choose a tool](#choose-a-tool)
- [🖥️ Interface preview](#interface-preview)
- [🔌 Before connecting](#before-connecting)

## Choose a tool

For third-party follower setups, see [cross-brand pairing resources](../integrations/README.md).

Choose a tool below, then follow its Wiki guide to launch the web interface or download the desktop software. The Wiki maintains current versions, compatibility details, and step-by-step instructions.

| Tool | Use it for | Guide and tool entry |
| --- | --- | --- |
| Star Arm 102 web control | LD / HD leader and FL follower connection, teleoperation, 3D pose display, and configuration | [Robot arm web control guide](https://fashionstar.com.hk/wiki/software/robot-arm/web-config-tool/) |
| UART / RS-485 servo web configuration | Servo detection, status readback, and parameter configuration | [Servo web configuration guide](https://fashionstar.com.hk/wiki/software/servo/web-config-tool/) |
| Windows bus servo software | Desktop servo control and configuration | [Desktop software guide and download](https://fashionstar.com.hk/wiki/software/servo/pc-config-software/) |

## Interface preview

Star Arm 102 web control interface with an LD model and no devices connected (https://fashionstar.com.hk/wiki/software/robot-arm/web-config-tool/)

English interface selected; 1920 × 1080 (16:9) desktop preview captured in Chrome on October 3, 2026 with no hardware connected. Interface details may change. Open the Wiki for current instructions and supported functions for your model.

## Before connecting

Read the tool's connection requirements and the [hardware setup guide](../docs/hardware-setup.md). The web tools recommend Chrome or Edge with Web Serial support. Check the servo model, protocol, adapter, and power supply before choosing a servo tool.

Tool applications, installers, and their dependencies are maintained outside this repository. This directory contains navigation only. Repository maintenance scripts are in [scripts](../scripts/README.md).

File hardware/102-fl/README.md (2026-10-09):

# Star Arm 102-FL hardware

[← Hardware Resources](../README.md)　|　<sub>**English** / [简体中文](README.zh.md)</sub>

<p align="center">
  <a href="https://fashionstar.com.hk/store/wp-content/uploads/2026/09/102-fl-diy-kit-main-image-01.webp">Star Arm 102-FL DIY kit</a>
  <a href="https://fashionstar.com.hk/store/wp-content/uploads/2026/06/102-fl-main-image-02.webp">Star Arm 102-FL product view 2</a>
  <a href="https://fashionstar.com.hk/store/wp-content/uploads/2026/06/102-fl-main-image-03.webp">Star Arm 102-FL product view 3</a>
  <a href="https://fashionstar.com.hk/store/wp-content/uploads/2026/06/102-fl-main-image-04.webp">Star Arm 102-FL product view 4</a>
  <a href="https://fashionstar.com.hk/store/wp-content/uploads/2026/06/102-fl-main-image-05.webp">Star Arm 102-FL product view 5</a>
  <a href="https://fashionstar.com.hk/store/wp-content/uploads/2026/06/102-fl-main-image-06.webp">Star Arm 102-FL product view 6</a>
</p>

**On this page:**

- [📂 Resources](#resources)
- [📋 Bill of Materials](#bill-of-materials)

## Resources

| Directory | Description | Status |
| --- | --- | --- |
| [assembly-guide/](assembly-guide/README.md) | Main arm assembly video | ✅ Video available<br>🟡 Revision and wiring coverage under review |
| [step/](step/) | Part models in parts/; whole-arm assemblies in assembly/ | ✅ Files available<br>🟡 Revision alignment under review |
| [printing/](printing/) | 3MF projects; STL: [View parts](printing/stl/) · [Download ZIP](printing/stl/star-arm-102-fl-stl.zip) | ✅ 11 individual 3MF files and combined project available; 11 STL files and ZIP available<br>🟡 Link1 settings conflict with BOM; physical print validation pending |
| [drawings/](drawings/) | PDF / DWG drawings | ✅ Reference files available<br>🟡 Revision under review |
| [robot-description/](robot-description/) | ROS 1 package: [Browse source](robot-description/) · [Download ZIP](robot-description/star-arm-102-fl-urdf.zip) | ✅ Source and ZIP available<br>🟡 Joint parameters and runtime pending validation |

## Bill of Materials

The table below lists **29 assembly items** for 102-FL. Missing images are marked pending.

Printed-part names match the STEP, STL, and individual 3MF filenames. Print settings in Notes are references pending physical print validation. The BOM specifies 5 wall loops / 50% infill for link1, while the supplied 3MF uses 2 / 15%; confirm before printing.

| No. | Name | Image | Description | Quantity | Notes |
| :---: | --- | :---: | --- | :---: | --- |
| 1 | RX8-U50H-M | Pending | Firmware V330 | 2 | Installed part |
| 2 | RA8-U35H-M | Pending | Firmware V225 | 3 | Installed part |
| 3 | RA8-U35H-M-C047 | Pending | Single-shaft rear cover; firmware V225 | 1 | Installed part |
| 4 | RA8-U27H-M-C005 | Pending | D-shaft, single-shaft rear cover; firmware V225 | 1 | Installed part |
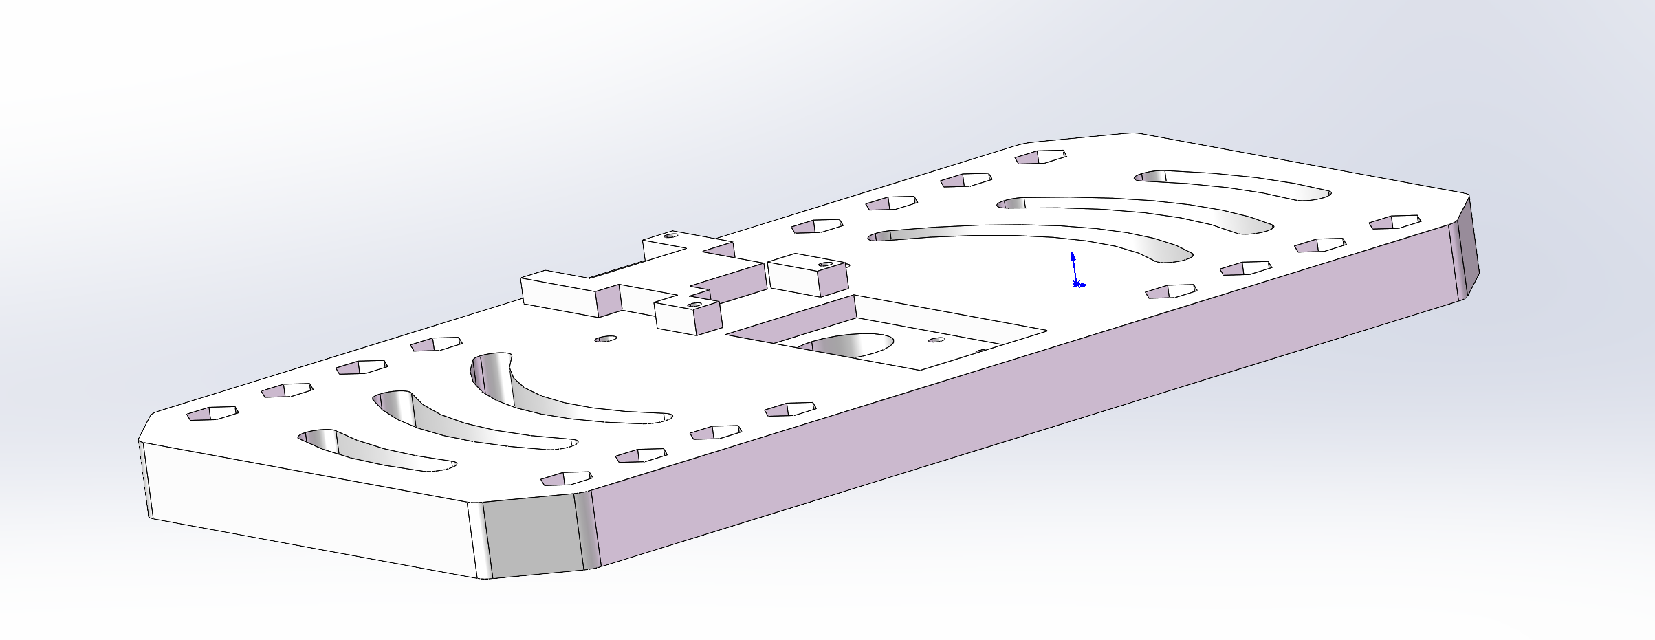
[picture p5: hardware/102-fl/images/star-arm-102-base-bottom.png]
star-arm-102-base-bottom
| 5 | star-arm-102-base-bottom |  | PLA 3D printed part (ivory) | 1 | 2 wall loops; 15% infill |
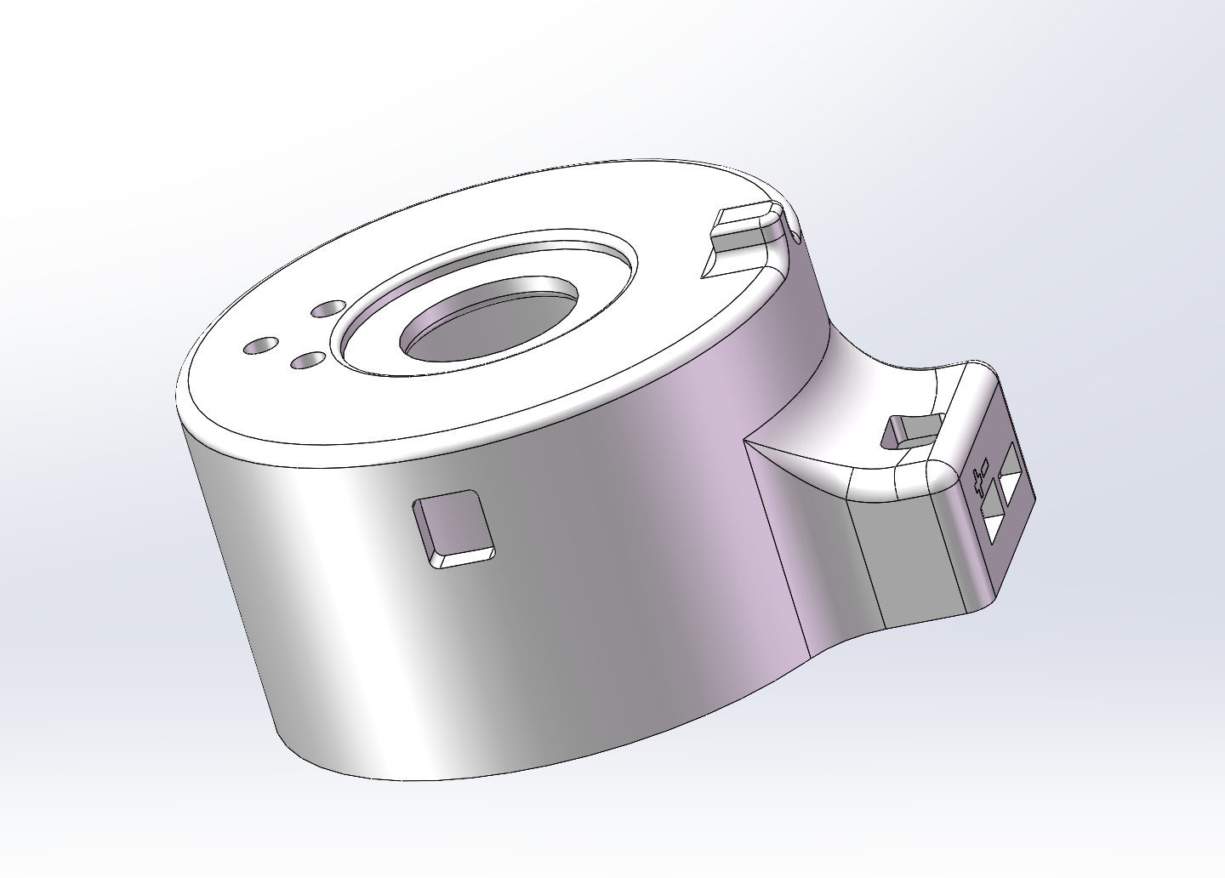
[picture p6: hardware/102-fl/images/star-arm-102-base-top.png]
star-arm-102-base-top
| 6 | star-arm-102-base-top |  | PLA 3D printed part (ivory) | 1 | Settings vary by region; see 3MF |
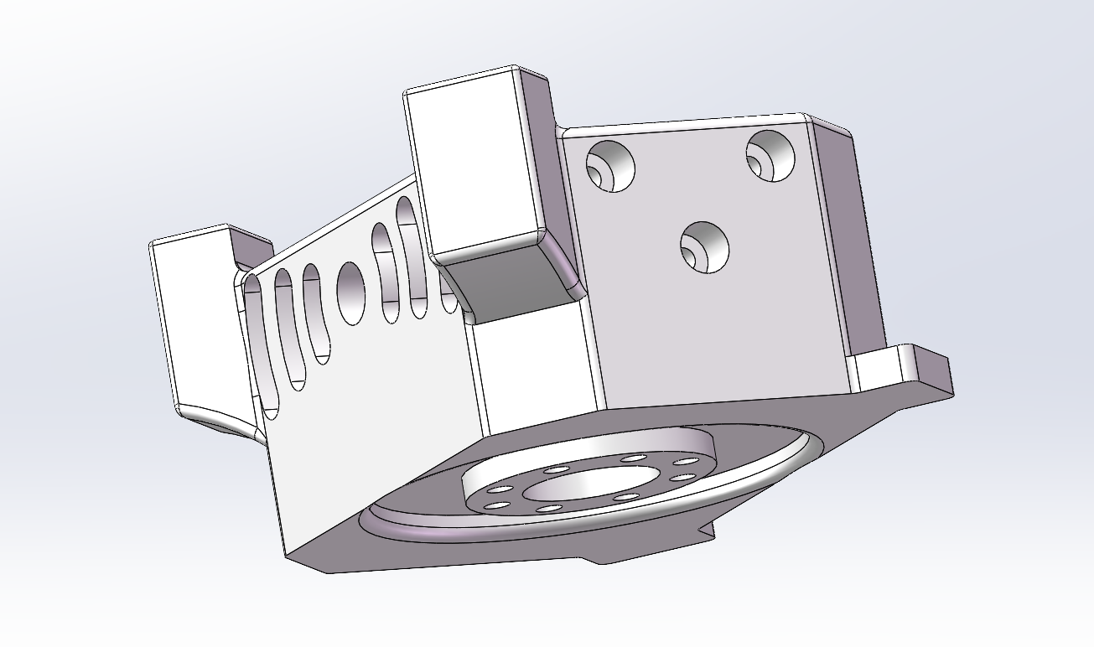
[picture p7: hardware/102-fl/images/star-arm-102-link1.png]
star-arm-102-link1
| 7 | star-arm-102-link1 |  | PLA 3D printed part (ivory) | 1 | 5 wall loops; 50% infill |
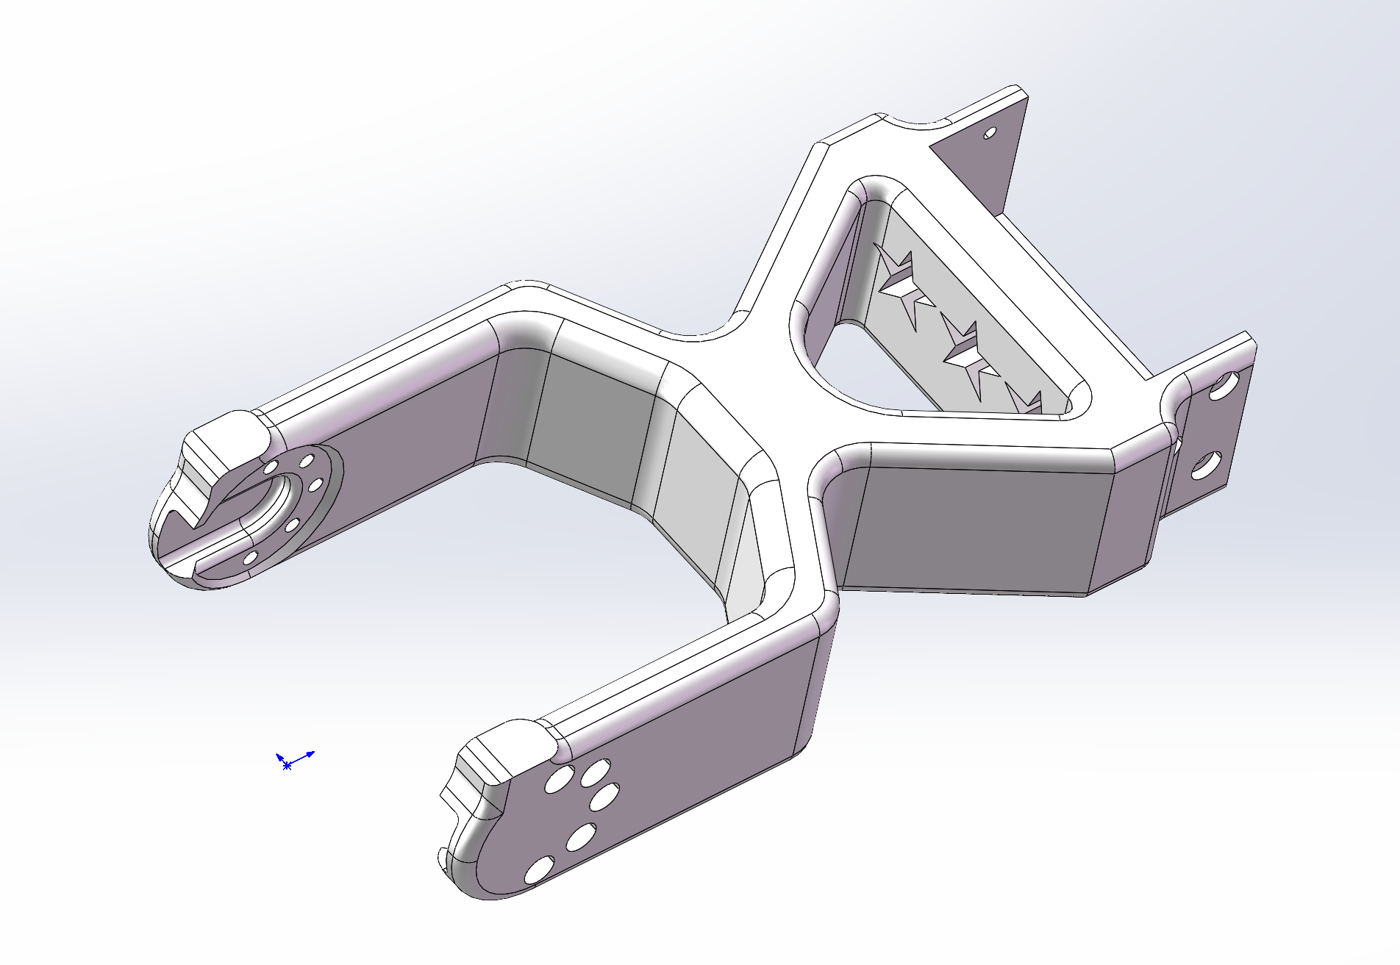
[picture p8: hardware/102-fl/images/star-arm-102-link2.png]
star-arm-102-link2
| 8 | star-arm-102-link2 |  | PLA 3D printed part (ivory) | 1 | 2 wall loops; 10% infill |
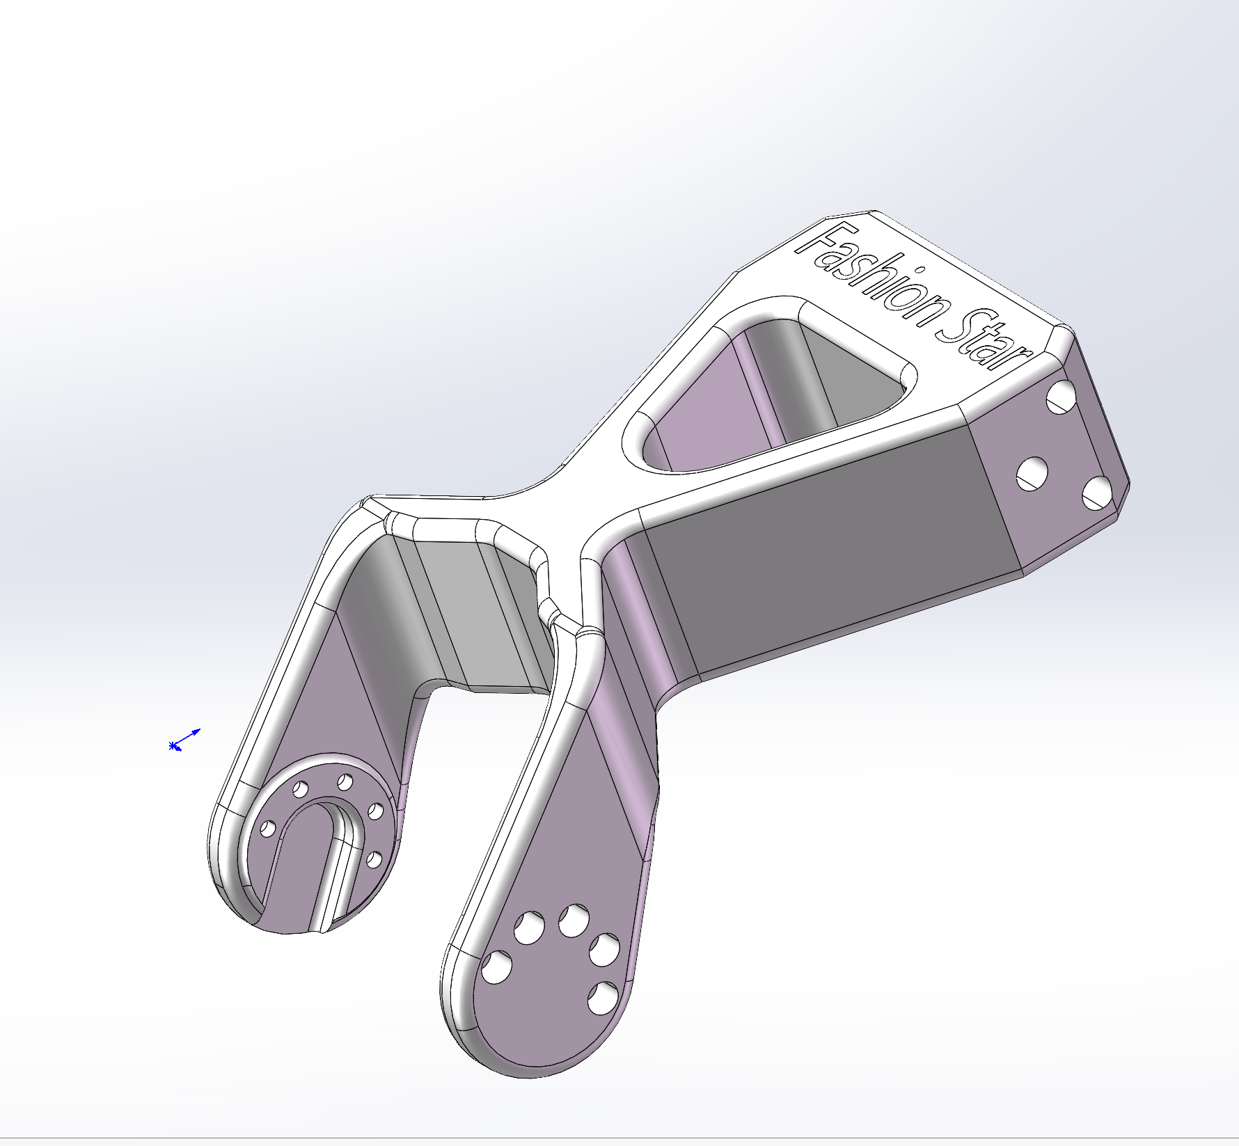
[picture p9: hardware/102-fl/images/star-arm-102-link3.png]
star-arm-102-link3
| 9 | star-arm-102-link3 |  | PLA 3D printed part (ivory + black) | 1 | Settings vary by region; see 3MF |
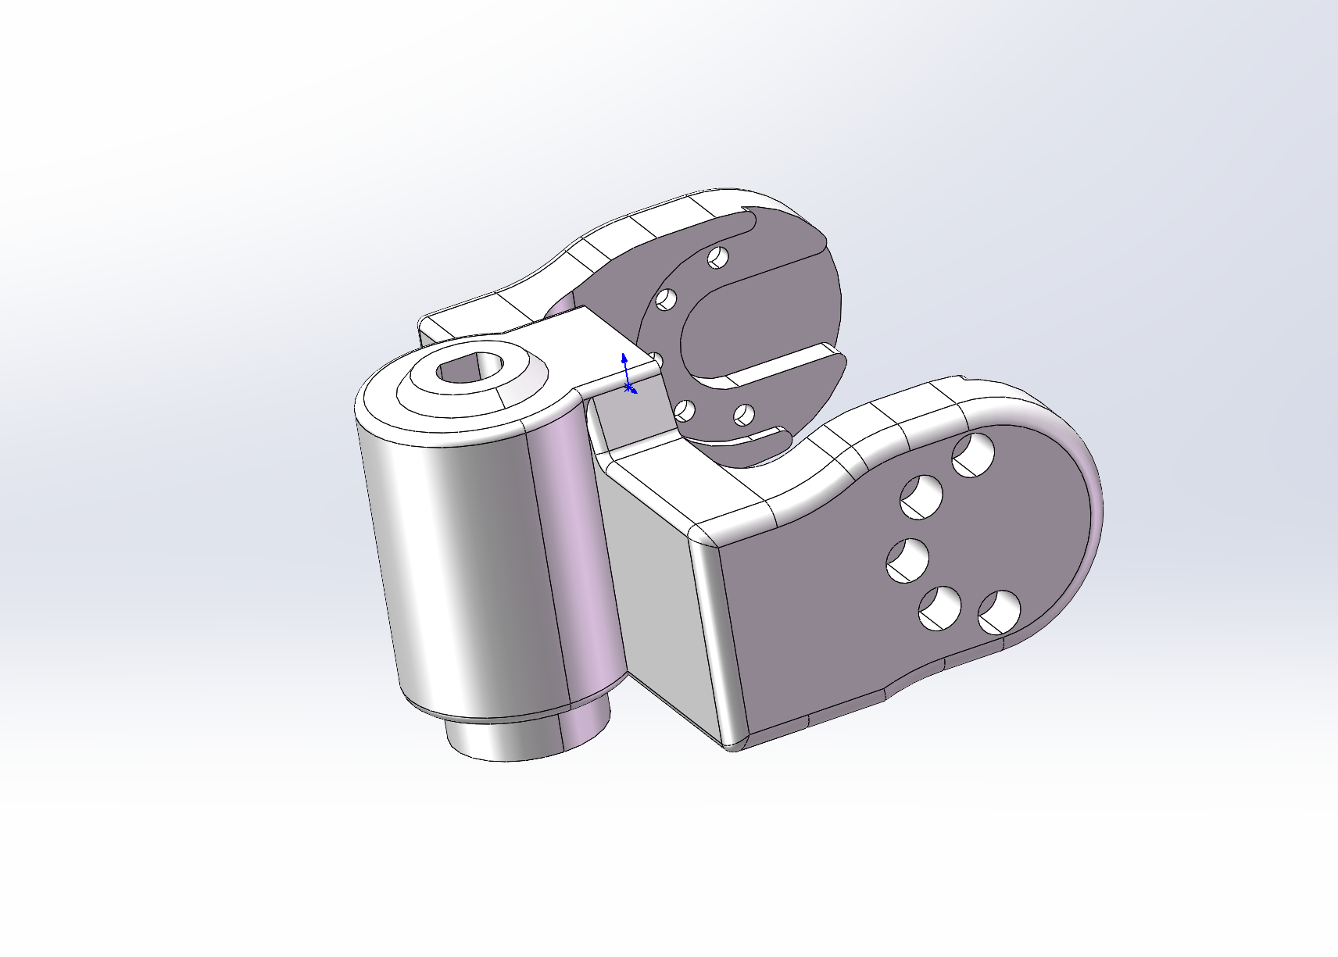
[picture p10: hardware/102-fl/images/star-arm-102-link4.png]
star-arm-102-link4
| 10 | star-arm-102-link4 |  | PLA 3D printed part (ivory) | 1 | 2 wall loops; 15% infill |
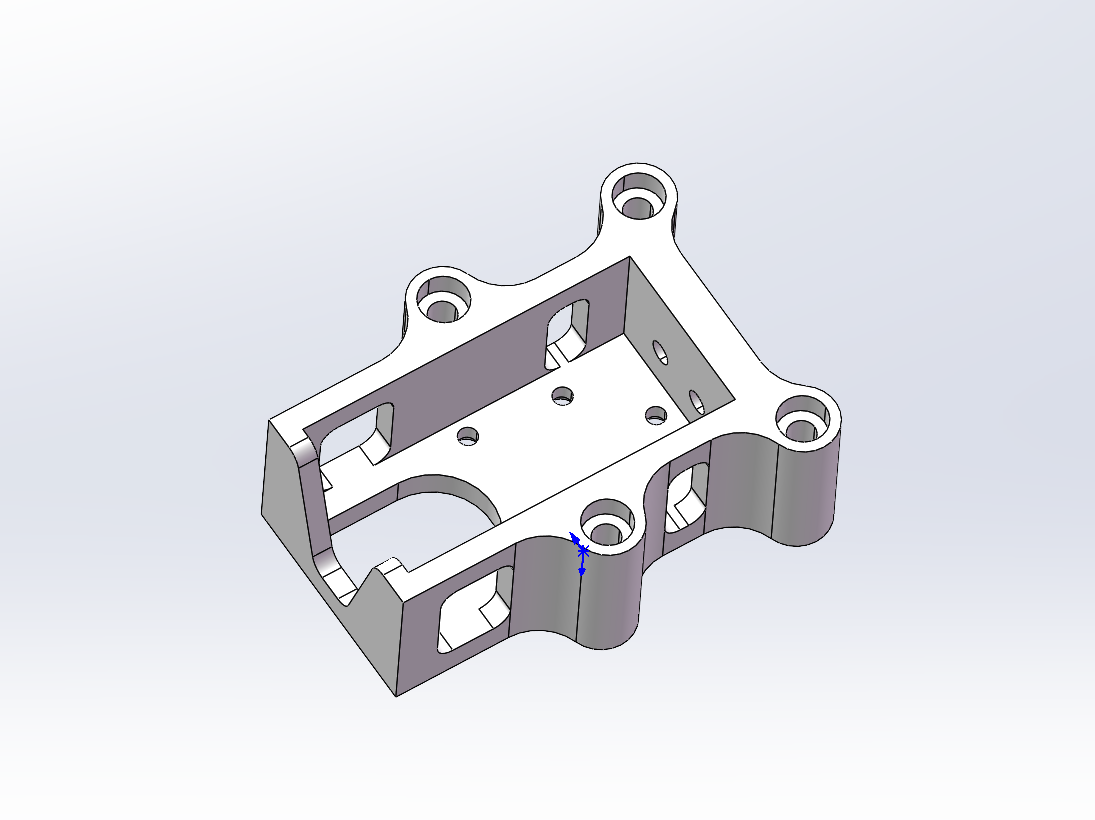
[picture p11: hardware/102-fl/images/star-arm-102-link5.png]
star-arm-102-link5
| 11 | star-arm-102-link5 |  | PLA 3D printed part (ivory) | 1 | 2 wall loops; 15% infill |
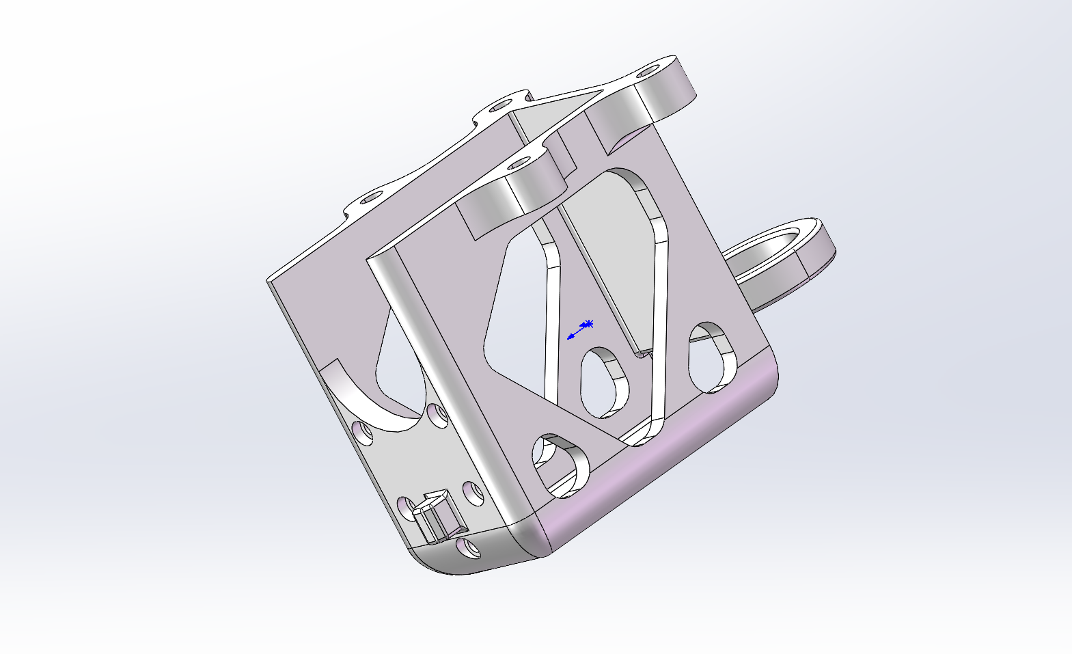
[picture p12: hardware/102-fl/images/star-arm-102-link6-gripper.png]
star-arm-102-link6-gripper
| 12 | star-arm-102-link6-gripper |  | PLA 3D printed part (ivory) | 1 | 4 wall loops; 15% infill |
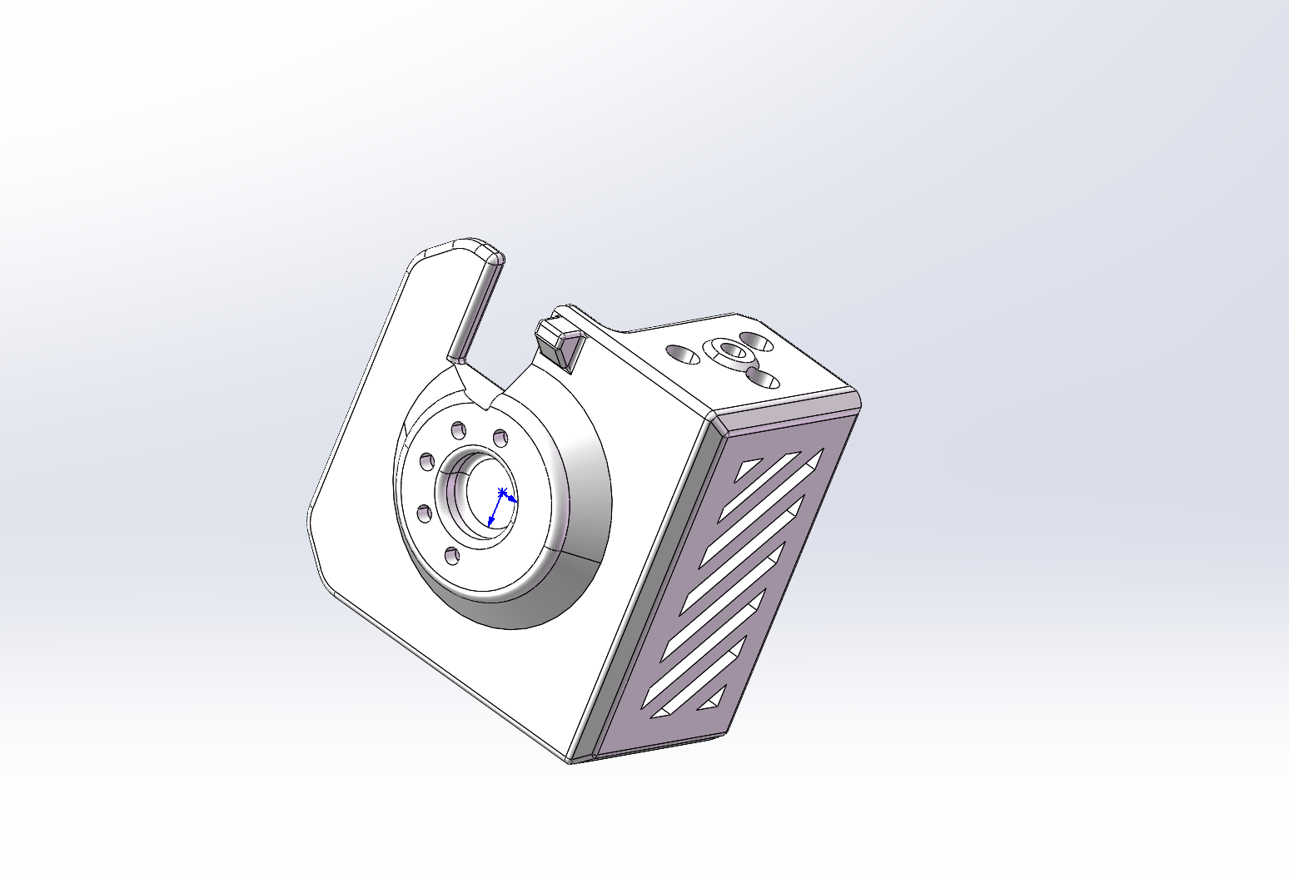
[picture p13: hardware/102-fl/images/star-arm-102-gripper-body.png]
star-arm-102-gripper-body
| 13 | star-arm-102-gripper-body |  | PLA 3D printed part (ivory) | 1 | 4 wall loops; 15% infill |
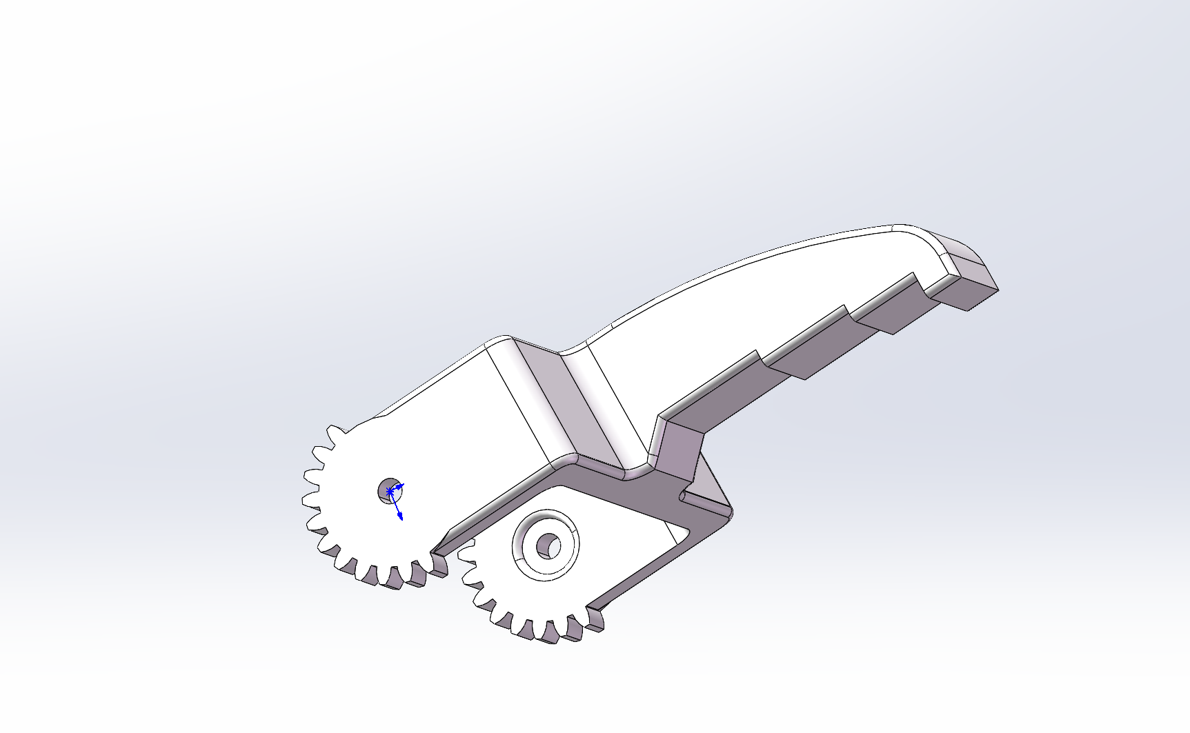
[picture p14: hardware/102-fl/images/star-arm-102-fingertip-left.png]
star-arm-102-fingertip-left
| 14 | star-arm-102-fingertip-left |  | PLA 3D printed part (ivory) | 1 | 4 wall loops; 15% infill |
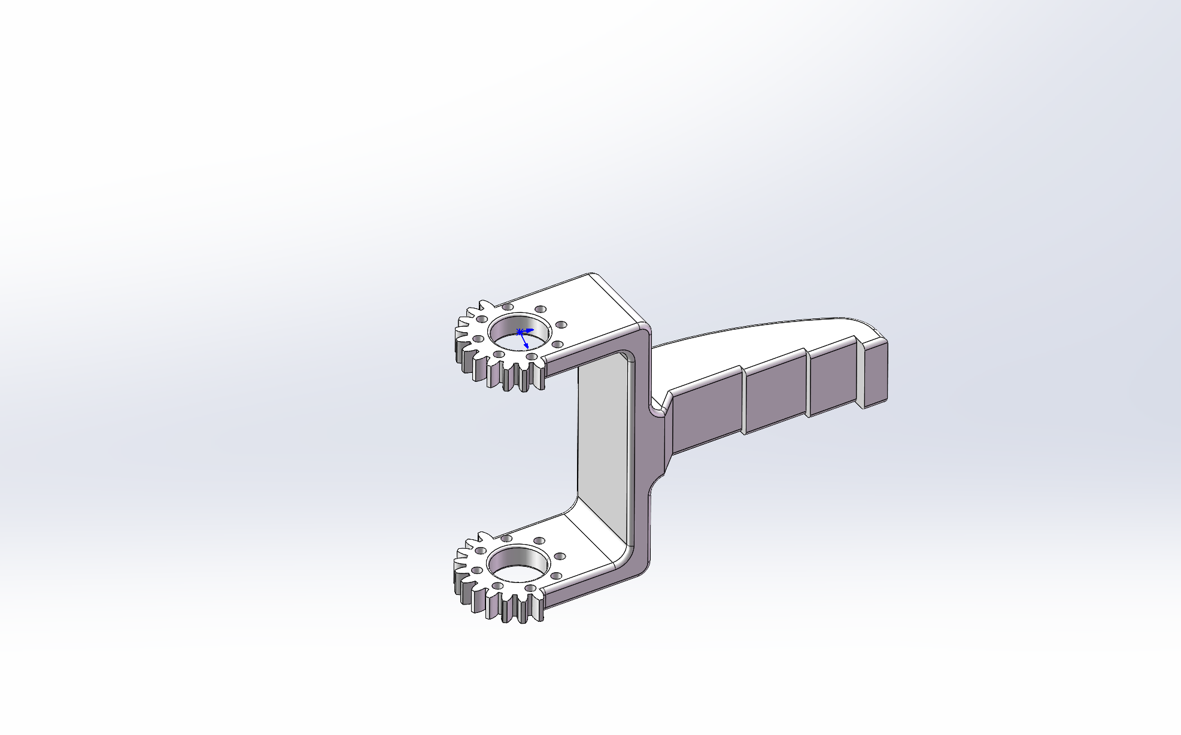
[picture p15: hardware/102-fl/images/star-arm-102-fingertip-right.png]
star-arm-102-fingertip-right
| 15 | star-arm-102-fingertip-right |  | PLA 3D printed part (ivory) | 1 | 4 wall loops; 15% infill |
| 16 | Thrust needle roller bearing | Pending | AXK2035 + 2AS | 1 | Installed part |
| 17 | UC-01 board | UC-01 | XT30 connector | 1 | Installed part |
| 18 | 120 mm servo cable | Pending | PH-3Y, reverse-wired ends, black braided silicone cable | 4 | Installed part |
| 19 | 200 mm servo cable | Pending | PH-3Y, reverse-wired ends, black braided silicone cable | 3 | Installed part |
| 20 | M3 × 10 socket-head screw | Pending | HSCS, grade 12.9 | 1 | Installed part |
| 21 | M3 × 22 socket-head screw | Pending | Black finish | 4 | Installed part |
| 22 | M3 × 10 Phillips screw | Pending | Hardened, black finish | 1 | Installed part |
| 23 | PB2.0 × 5 self-tapping screw | Pending | Phillips countersunk, hardened, black finish | 30 | Installed part |
| 24 | M2 × 4.5 Phillips screw | Pending | Countersunk, black finish, pre-applied threadlocker | 47 | Installed part |
| 25 | M2 × 10 socket-head screw | Pending | Black finish | 8 | Installed part |
| 26 | M2 × 8 socket-head screw | Pending | Black finish | 16 | Installed part |
| 27 | M3 × 12 self-tapping screw | Pending | Phillips head | 2 | Installed part |
| 28 | M3 locknut | Pending | Black finish | 6 | Installed part |
| 29 | M3 washer | Pending | 3 × 6 × 0.5 mm | 2 | Installed part |

Found an error in these resources or need help? Contact our [Support Hub](https://fashionstar.com.hk/support/) with your model and the relevant file or item.

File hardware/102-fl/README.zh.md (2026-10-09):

# Star Arm 102-FL 硬件

[← 硬件资源](../README.zh.md)　|　<sub>[English](README.md) / **简体中文**</sub>

<p align="center">
  <a href="https://fashionstar.com.hk/store/wp-content/uploads/2026/09/102-fl-diy-kit-main-image-01.webp">Star Arm 102-FL DIY 套件</a>
  <a href="https://fashionstar.com.hk/store/wp-content/uploads/2026/06/102-fl-main-image-02.webp">Star Arm 102-FL 产品图片 2</a>
  <a href="https://fashionstar.com.hk/store/wp-content/uploads/2026/06/102-fl-main-image-03.webp">Star Arm 102-FL 产品图片 3</a>
  <a href="https://fashionstar.com.hk/store/wp-content/uploads/2026/06/102-fl-main-image-04.webp">Star Arm 102-FL 产品图片 4</a>
  <a href="https://fashionstar.com.hk/store/wp-content/uploads/2026/06/102-fl-main-image-05.webp">Star Arm 102-FL 产品图片 5</a>
  <a href="https://fashionstar.com.hk/store/wp-content/uploads/2026/06/102-fl-main-image-06.webp">Star Arm 102-FL 产品图片 6</a>
</p>

**本页导航：**

- [📂 资源目录](#resources)
- [📋 物料清单](#bill-of-materials)

## 资源目录

| 目录 | 内容 | 状态 |
| --- | --- | --- |
| [assembly-guide/](assembly-guide/README.zh.md) | 主体机械臂装配视频 | ✅ 视频已提供<br>🟡 版本及接线覆盖待核对 |
| [step/](step/) | parts/ 零件模型；assembly/ 整机装配模型 | ✅ 文件已提供<br>🟡 配套版本待核对 |
| [printing/](printing/) | 3MF 打印项目；STL：[查看零件](printing/stl/) · [下载整套 ZIP](printing/stl/star-arm-102-fl-stl.zip) | ✅ 11 个独立零件 3MF 及整套项目已提供；11 个 STL 及整套 ZIP 已提供<br>🟡 link1 参数与 BOM 冲突；实物打印待验证 |
| [drawings/](drawings/) | PDF／DWG 图纸 | ✅ 参考文件已提供<br>🟡 版本待核对 |
| [robot-description/](robot-description/) | ROS 1 软件包：[浏览源码](robot-description/) · [下载 ZIP](robot-description/star-arm-102-fl-urdf.zip) | ✅ 源码与 ZIP 已提供<br>🟡 关节参数及运行待验证 |

## 物料清单

下表列出 102-FL 的 **29 项装机物料**；无图片的条目标为待补。

打印件名称与 STEP、STL 及独立 3MF 文件名一致。备注中的打印参数仅供参考，尚未完成实物打印验证。link1 的 BOM 参数为壁数 5／填充 50%，而原 3MF 为壁数 2／填充 15%，打印前需确认。

| 序号 | 名称 | 图片 | 描述 | 数量 | 备注 |
| :---: | --- | :---: | --- | :---: | --- |
| 1 | RX8-U50H-M | 待补 | RX8-U50H-M  半成品舵机，固件版本V330 | 2 | 装机件 |
| 2 | RA8-U35H-M | 待补 | RA8-U35H-M  固件版本V225 | 3 | 装机件 |
| 3 | RA8-U35H-M-C047 | 待补 | 半成品舵机，单轴后盖，固件版本V225 | 1 | 装机件 |
| 4 | RA8-U27H-M-C005 | 待补 | 半成品舵机，单轴后盖，D轴，固件版本V225 | 1 | 装机件 |
| 5 | star-arm-102-base-bottom | star-arm-102-base-bottom | PLA 3D 打印件（象牙白） | 1 | 壁数 2；填充 15% |
| 6 | star-arm-102-base-top | star-arm-102-base-top | PLA 3D 打印件（象牙白） | 1 | 分区域参数，详见 3MF |
| 7 | star-arm-102-link1 | star-arm-102-link1 | PLA 3D 打印件（象牙白） | 1 | 壁数 5；填充 50% |
| 8 | star-arm-102-link2 | star-arm-102-link2 | PLA 3D 打印件（象牙白） | 1 | 壁数 2；填充 10% |
| 9 | star-arm-102-link3 | star-arm-102-link3 | PLA 3D 打印件（象牙白＋黑色） | 1 | 分区域参数，详见 3MF |
| 10 | star-arm-102-link4 | star-arm-102-link4 | PLA 3D 打印件（象牙白） | 1 | 壁数 2；填充 15% |
| 11 | star-arm-102-link5 | star-arm-102-link5 | PLA 3D 打印件（象牙白） | 1 | 壁数 2；填充 15% |
| 12 | star-arm-102-link6-gripper | star-arm-102-link6-gripper | PLA 3D 打印件（象牙白） | 1 | 壁数 4；填充 15% |
| 13 | star-arm-102-gripper-body | star-arm-102-gripper-body | PLA 3D 打印件（象牙白） | 1 | 壁数 4；填充 15% |
| 14 | star-arm-102-fingertip-left | star-arm-102-fingertip-left | PLA 3D 打印件（象牙白） | 1 | 壁数 4；填充 15% |
| 15 | star-arm-102-fingertip-right | star-arm-102-fingertip-right | PLA 3D 打印件（象牙白） | 1 | 壁数 4；填充 15% |
| 16 | 滚针轴承 | 待补 | AXK2035+2AS | 1 | 装机件 |
| 17 | PCBA | UC-01 | UC-01 XT30 | 1 | 装机件 |
| 18 | 线材 | 待补 | PH-3Y 双头反向60芯 0.08 黑色硅胶排线L=120 mm  黑色编织线 | 4 | 装机件 |
| 19 | 线材 | 待补 | PH-3Y 双头反向60芯 0.08 黑色硅胶排线L=200 mm  黑色编织线 | 3 | 装机件 |
| 20 | 螺丝 | 待补 | HSCS M3*10 12.9级内六角圆柱头螺钉 | 1 | 装机件 |
| 21 | 螺丝 | 待补 | M3*22黑色内六角 | 4 | 装机件 |
| 22 | 螺丝 | 待补 | M3*10加硬包黑十字槽螺杆 | 1 | 装机件 |
| 23 | 螺丝 | 待补 | PB2.0*5 自攻十字槽加硬包黑沉头螺杆 | 30 | 装机件 |
| 24 | 螺丝 | 待补 | M2*4.5 预点胶十字槽螺杆黑色沉头 | 47 | 装机件 |
| 25 | 螺丝 | 待补 | M2*10 黑色内六角 | 8 | 装机件 |
| 26 | 螺丝 | 待补 | M2*8 黑色内六角 | 16 | 装机件 |
| 27 | 螺丝 | 待补 | M3*12自攻十字槽螺杆 | 2 | 装机件 |
| 28 | 螺母 | 待补 | M3防松螺母 黑色 | 6 | 装机件 |
| 29 | 垫片 | 待补 | M3*6*0.5 | 2 | 装机件 |

发现资料错误或需要帮助？请通过 [Support 支持中心](https://fashionstar.com.hk/support/) 联系我们，并注明型号及对应文件或条目。

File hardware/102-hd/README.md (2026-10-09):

# Star Arm 102-HD hardware

[← Hardware Resources](../README.md)　|　<sub>**English** / [简体中文](README.zh.md)</sub>

<p align="center">
  <a href="https://fashionstar.com.hk/store/wp-content/uploads/2026/09/102-hd-diy-kit-main-image-01.webp">Star Arm 102-HD DIY kit</a>
  <a href="https://fashionstar.com.hk/store/wp-content/uploads/2026/06/102-hd-main-image-02-1.webp">Star Arm 102-HD product view 2</a>
  <a href="https://fashionstar.com.hk/store/wp-content/uploads/2026/06/102-hd-main-image-04-1.webp">Star Arm 102-HD product view 3</a>
  <a href="https://fashionstar.com.hk/store/wp-content/uploads/2026/06/102-hd-main-image-05-1.webp">Star Arm 102-HD product view 4</a>
  <a href="https://fashionstar.com.hk/store/wp-content/uploads/2026/06/102-hd-main-image-06.webp">Star Arm 102-HD product view 5</a>
  <a href="https://fashionstar.com.hk/store/wp-content/uploads/2026/06/102-hd-main-image-07.webp">Star Arm 102-HD product view 6</a>
</p>

**On this page:**

- [📂 Resources](#resources)
- [📋 Bill of Materials](#bill-of-materials)

## Resources

| Directory | Description | Status |
| --- | --- | --- |
| [assembly-guide/](assembly-guide/README.md) | LD assembly video with HD servo substitution | ✅ Video available<br>🟡 HD button instructions pending; revision and wiring coverage under review |
| [step/](step/) | Part models in parts/; shared assembly in assembly/ | ✅ Files available<br>🟡 Revision alignment under review |
| [printing/](printing/) | 3MF projects; STL: [View parts](printing/stl/) · [Download ZIP](printing/stl/star-arm-102-hd-stl.zip) | ✅ 13 individual 3MF files and combined project available; 13 STL files and ZIP available<br>🟡 Print validation pending |
| [drawings/](../102-ld/drawings/) | Shared LD body reference (PDF / DWG) | 🟡 HD-specific drawings to be added |
| [robot-description/](robot-description/) | ROS 1 package: [Browse source](robot-description/) · [Download ZIP](robot-description/star-arm-102-ld-hd-urdf.zip) | ✅ Source and ZIP available<br>🟡 Fixed joint5 definition, HD dynamics and runtime pending validation |

## Bill of Materials

The table below lists **31 assembly items** for 102-HD. Missing images are marked pending.

Printed-part names match the STEP, STL, and individual 3MF filenames. Print settings in Notes are references pending physical print validation.

| No. | Name | Image | Description | Quantity | Notes |
| :---: | --- | :---: | --- | :---: | --- |
| 1 | RP8-U45H-M | Pending | Firmware V225 | 4 | Installed part |
| 2 | RP8-U45H-M-C028 | Pending | Single-shaft rear cover; firmware V225 | 2 | Installed part |
| 3 | RP8-U45H-M-C029 | Pending | D-shaft, single-shaft rear cover; firmware V225 | 1 | Installed part |
| 4 | star-arm-102-base-bottom | star-arm-102-base-bottom | PLA 3D printed part (ivory) | 1 | 2 wall loops; 15% infill |
| 5 | star-arm-102-base-top | star-arm-102-base-top | PLA 3D printed part (ivory) | 1 | Settings vary by region; see 3MF |
| 6 | star-arm-102-link1 | star-arm-102-link1 | PLA 3D printed part (ivory) | 1 | 5 wall loops; 50% infill |
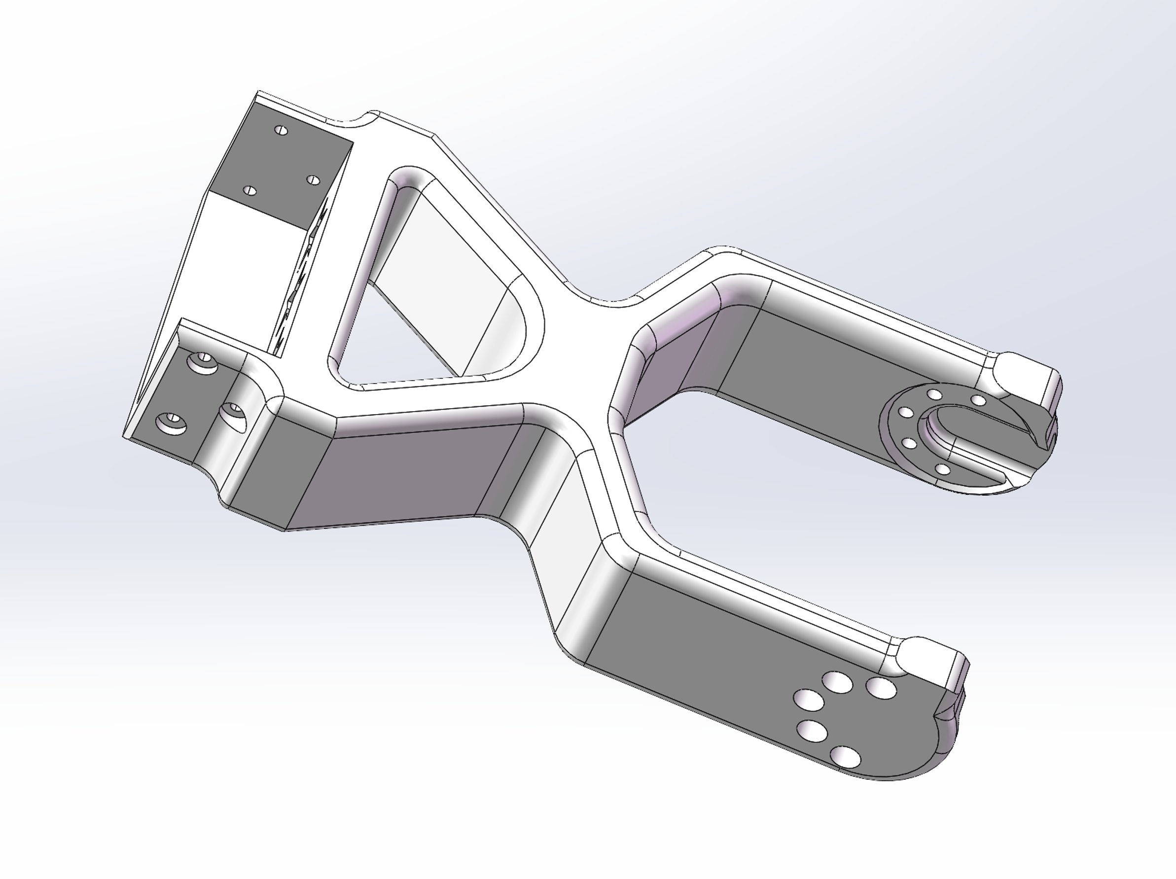
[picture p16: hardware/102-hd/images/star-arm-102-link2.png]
star-arm-102-link2
| 7 | star-arm-102-link2 |  | PLA 3D printed part (ivory) | 1 | 2 wall loops; 10% infill |
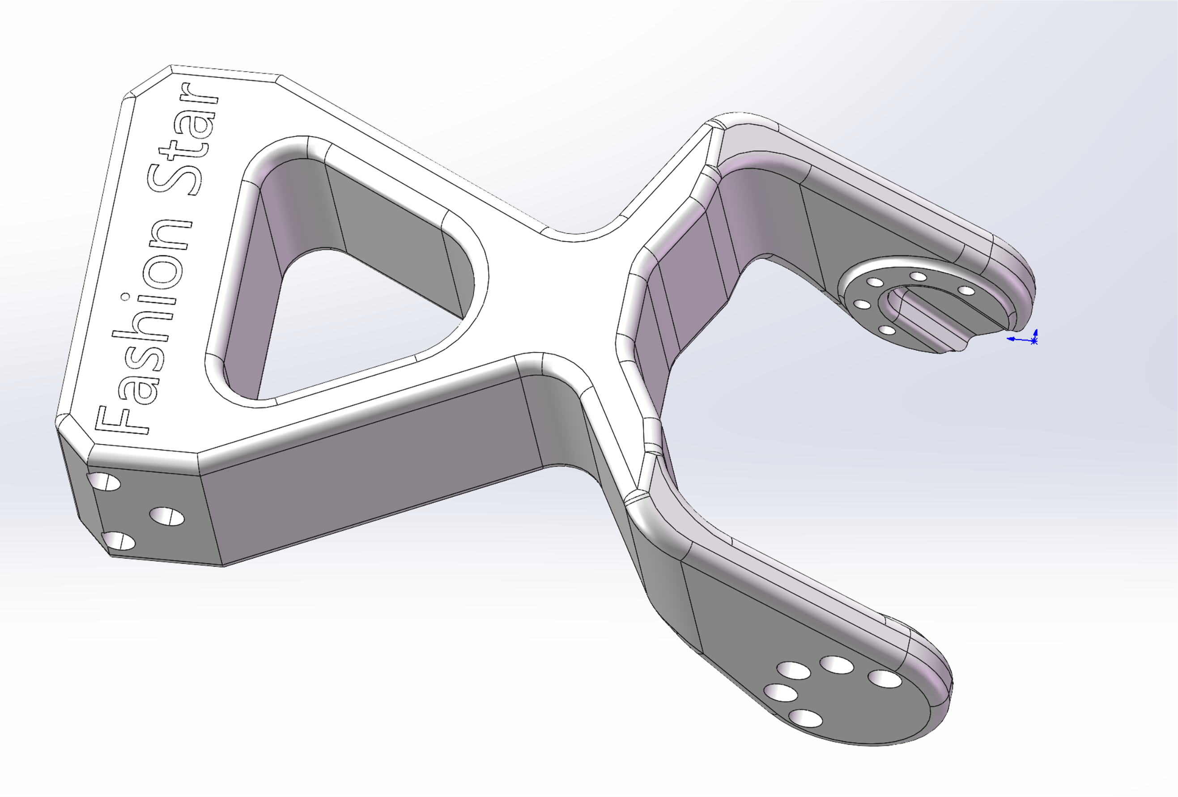
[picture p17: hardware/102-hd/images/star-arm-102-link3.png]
star-arm-102-link3
| 8 | star-arm-102-link3 |  | PLA 3D printed part (ivory + black) | 1 | Settings vary by region; see 3MF |
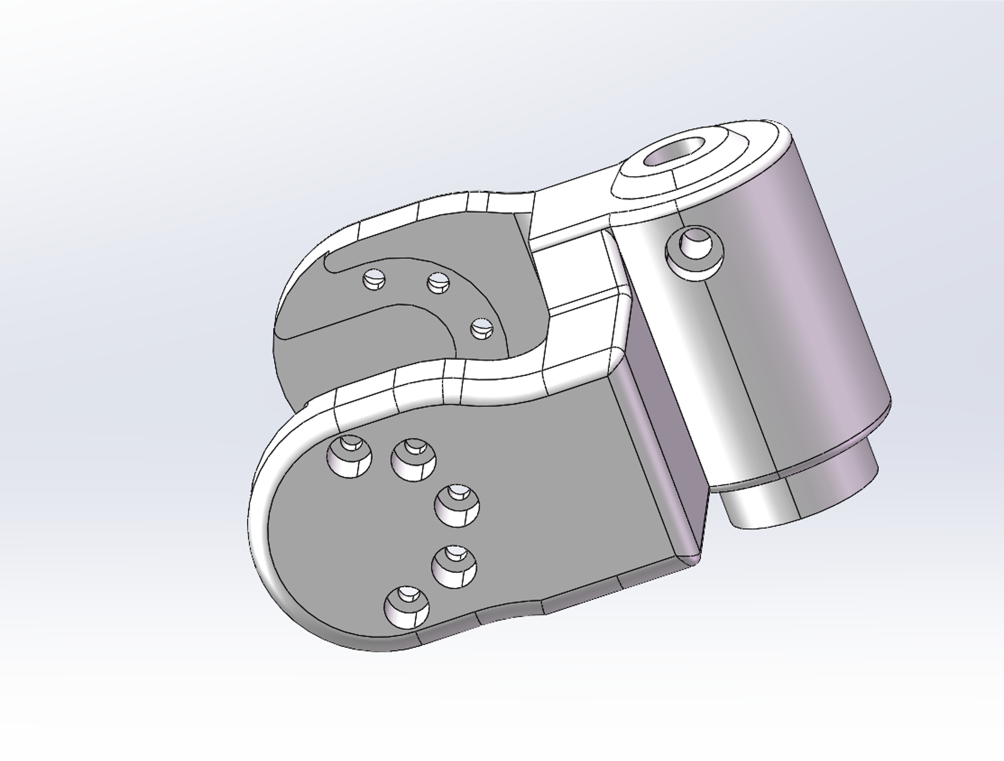
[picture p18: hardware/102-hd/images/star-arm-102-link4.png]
star-arm-102-link4
| 9 | star-arm-102-link4 |  | PLA 3D printed part (ivory) | 1 | 2 wall loops; 15% infill |
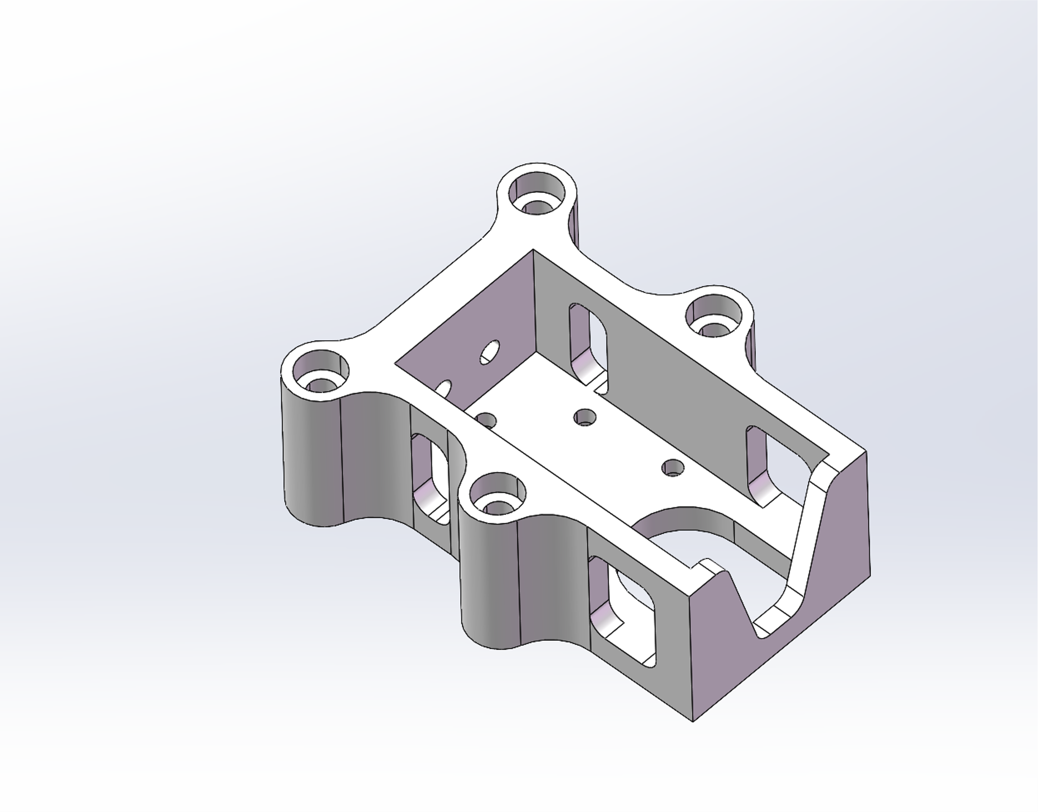
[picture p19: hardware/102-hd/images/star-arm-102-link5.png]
star-arm-102-link5
| 10 | star-arm-102-link5 |  | PLA 3D printed part (ivory) | 1 | 2 wall loops; 15% infill |
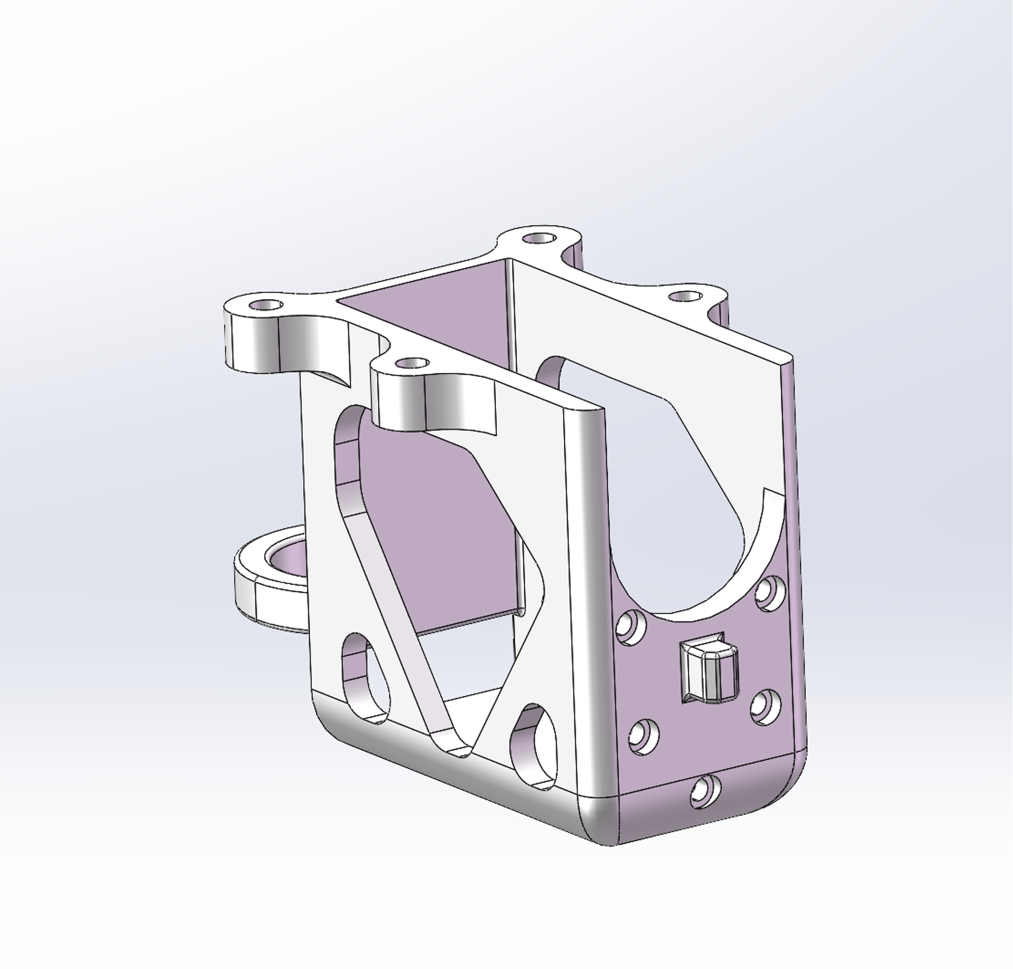
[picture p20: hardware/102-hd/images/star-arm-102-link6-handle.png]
star-arm-102-link6-handle
| 11 | star-arm-102-link6-handle |  | PLA 3D printed part (ivory) | 1 | 5 wall loops; 15% infill |
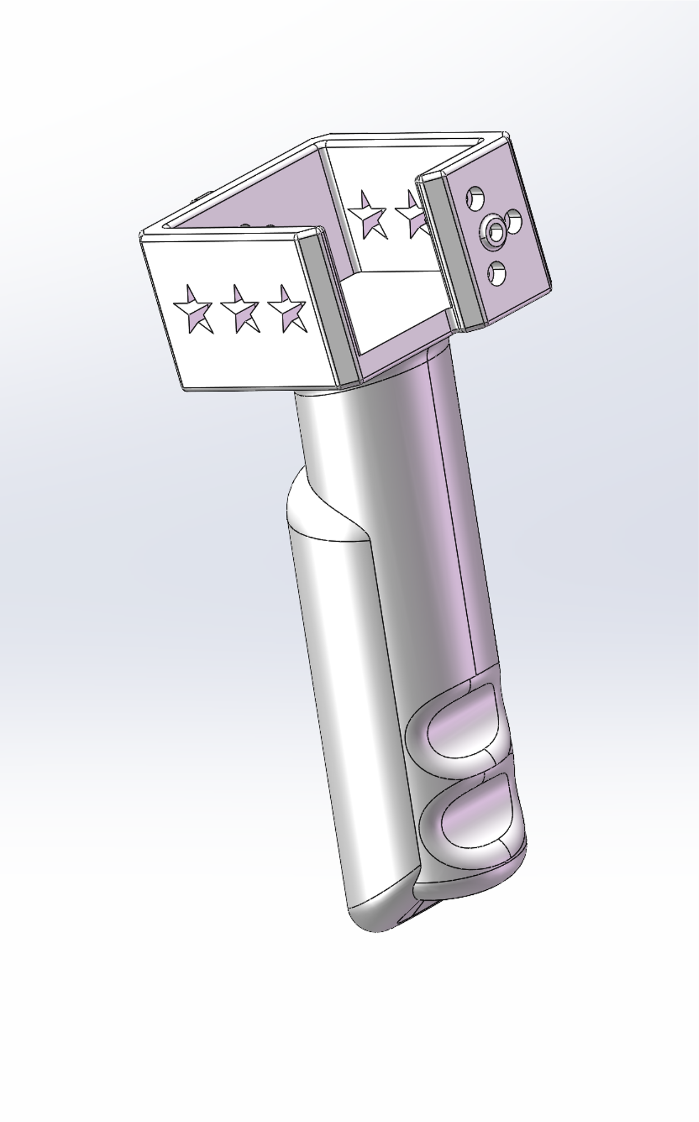
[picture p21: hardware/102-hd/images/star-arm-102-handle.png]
star-arm-102-handle
| 12 | star-arm-102-handle |  | PLA 3D printed part (ivory) | 1 | 2 wall loops; 15% infill |
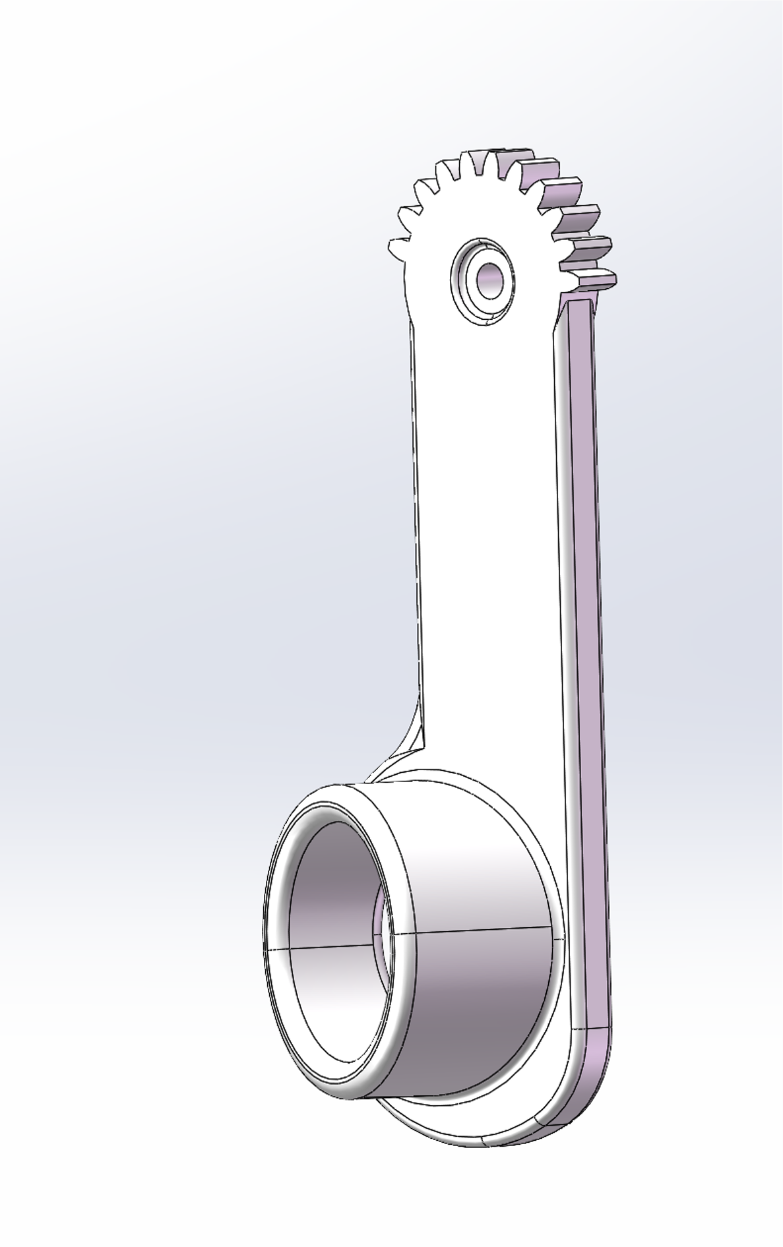
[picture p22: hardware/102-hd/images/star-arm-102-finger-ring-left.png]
star-arm-102-finger-ring-left
| 13 | star-arm-102-finger-ring-left |  | PLA 3D printed part (ivory) | 1 | 2 wall loops; 15% infill |
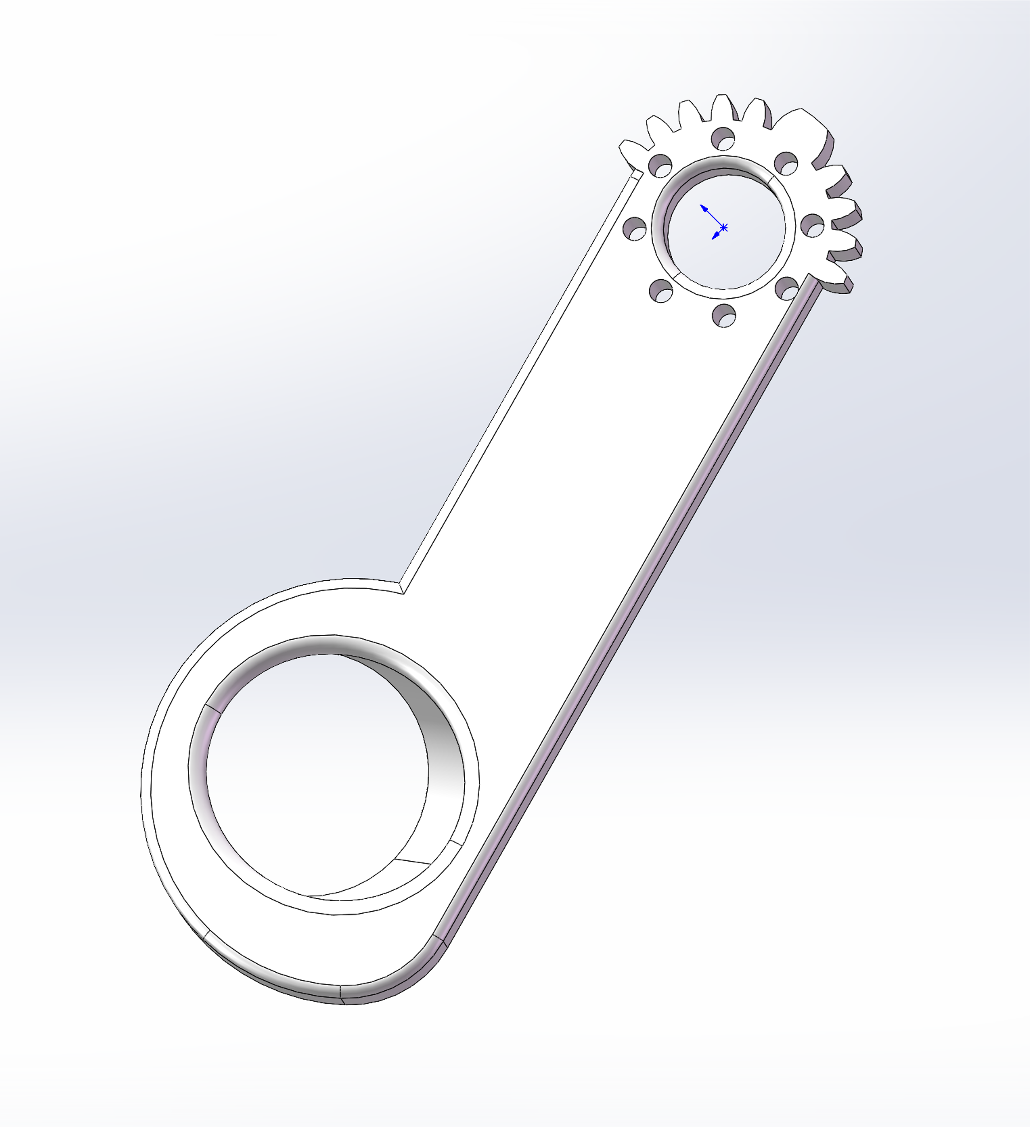
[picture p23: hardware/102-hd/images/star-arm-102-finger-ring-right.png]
star-arm-102-finger-ring-right
| 14 | star-arm-102-finger-ring-right |  | PLA 3D printed part (ivory) | 1 | 2 wall loops; 15% infill |
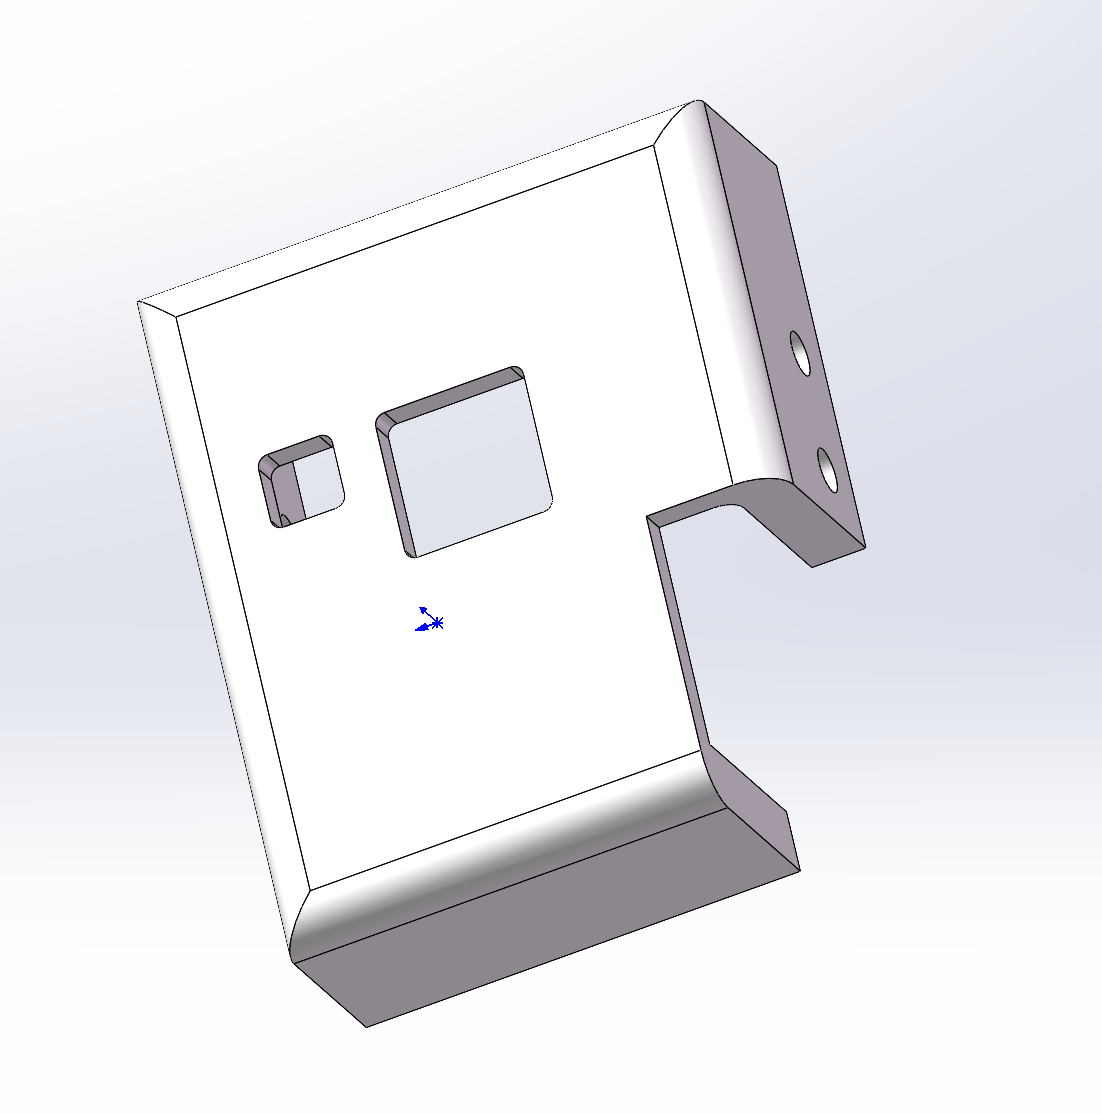
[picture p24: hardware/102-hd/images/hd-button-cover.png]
hd-button-cover
| 15 | hd-button-cover |  | PLA 3D printed part (ivory) | 1 | 2 wall loops; 15% infill |
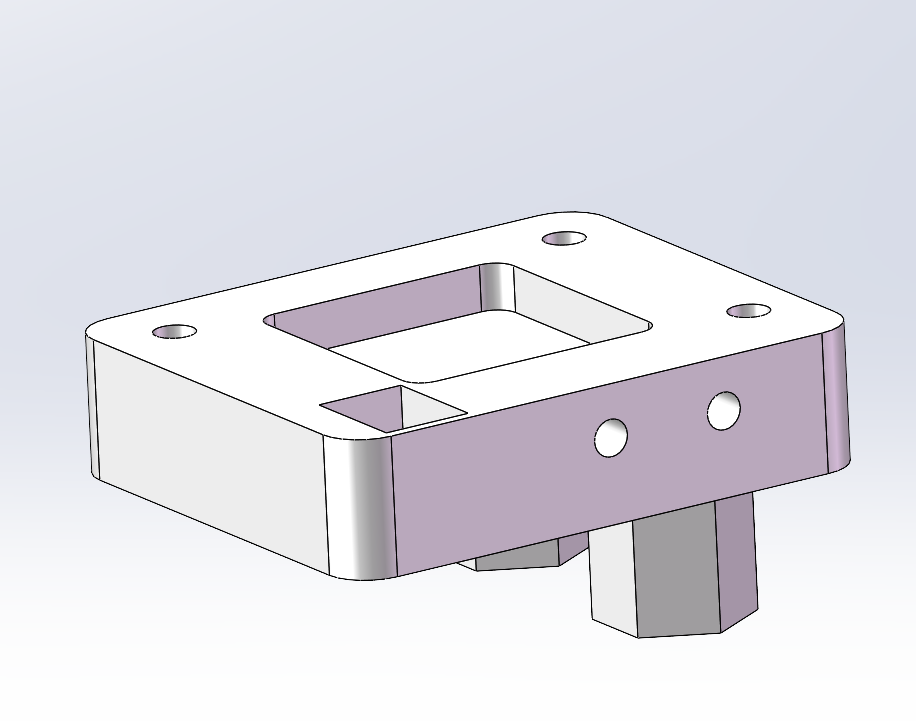
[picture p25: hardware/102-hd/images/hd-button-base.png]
hd-button-base
| 16 | hd-button-base |  | PLA 3D printed part (ivory) | 1 | 2 wall loops; 15% infill |
| 17 | UC-01 board | UC-01 | XT30 connector | 1 | Installed part |
| 18 | UK-01 board | Pending | With socket | 1 | Installed part |
| 19 | Thrust needle roller bearing | Pending | AXK2035 + 2AS | 1 | Installed part |
| 20 | 120 mm servo cable | Pending | PH-3Y, reverse-wired ends, black braided silicone cable | 6 | Installed part |
| 21 | 200 mm servo cable | Pending | PH-3Y, reverse-wired ends, black braided silicone cable | 2 | Installed part |
| 22 | M3 × 10 socket-head screw | Pending | HSCS, grade 12.9 | 1 | Installed part |
| 23 | M3 × 22 socket-head screw | Pending | Black finish | 4 | Installed part |
| 24 | M3 × 10 Phillips screw | Pending | Hardened, black finish | 1 | Installed part |
| 25 | PB2.0 × 5 self-tapping screw | Pending | Phillips countersunk, hardened, black finish | 46 | Installed part |
| 26 | M2 × 4.5 Phillips screw | Pending | Countersunk, black finish, pre-applied threadlocker | 35 | Installed part |
| 27 | M2 × 10 socket-head screw | Pending | Black finish | 8 | Installed part |
| 28 | M2 × 8 socket-head screw | Pending | Black finish | 8 | Installed part |
| 29 | M3 × 12 self-tapping screw | Pending | Phillips head | 2 | Installed part |
| 30 | M3 locknut | Pending | Black finish | 5 | Installed part |
| 31 | M3 washer | Pending | Stainless steel | 1 | Installed part |

Found an error in these resources or need help? Contact our [Support Hub](https://fashionstar.com.hk/support/) with your model and the relevant file or item.

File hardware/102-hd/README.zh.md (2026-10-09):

# Star Arm 102-HD 硬件

[← 硬件资源](../README.zh.md)　|　<sub>[English](README.md) / **简体中文**</sub>

<p align="center">
  <a href="https://fashionstar.com.hk/store/wp-content/uploads/2026/09/102-hd-diy-kit-main-image-01.webp">Star Arm 102-HD DIY 套件</a>
  <a href="https://fashionstar.com.hk/store/wp-content/uploads/2026/06/102-hd-main-image-02-1.webp">Star Arm 102-HD 产品图片 2</a>
  <a href="https://fashionstar.com.hk/store/wp-content/uploads/2026/06/102-hd-main-image-04-1.webp">Star Arm 102-HD 产品图片 3</a>
  <a href="https://fashionstar.com.hk/store/wp-content/uploads/2026/06/102-hd-main-image-05-1.webp">Star Arm 102-HD 产品图片 4</a>
  <a href="https://fashionstar.com.hk/store/wp-content/uploads/2026/06/102-hd-main-image-06.webp">Star Arm 102-HD 产品图片 5</a>
  <a href="https://fashionstar.com.hk/store/wp-content/uploads/2026/06/102-hd-main-image-07.webp">Star Arm 102-HD 产品图片 6</a>
</p>

**本页导航：**

- [📂 资源目录](#resources)
- [📋 物料清单](#bill-of-materials)

## 资源目录

| 目录 | 内容 | 状态 |
| --- | --- | --- |
| [assembly-guide/](assembly-guide/README.zh.md) | 参考 LD 视频并替换 HD 舵机 | ✅ 视频已提供<br>🟡 HD 按钮说明待补；版本及接线覆盖待核对 |
| [step/](step/) | parts/ 零件模型；assembly/ 共用装配模型 | ✅ 文件已提供<br>🟡 配套版本待核对 |
| [printing/](printing/) | 3MF 打印项目；STL：[查看零件](printing/stl/) · [下载整套 ZIP](printing/stl/star-arm-102-hd-stl.zip) | ✅ 13 个独立零件 3MF 及整套项目已提供；13 个 STL 及整套 ZIP 已提供<br>🟡 打印待验证 |
| [drawings/](../102-ld/drawings/) | LD 共用主体参考图（PDF／DWG） | 🟡 HD 专用图纸待提供 |
| [robot-description/](robot-description/) | ROS 1 软件包：[浏览源码](robot-description/) · [下载 ZIP](robot-description/star-arm-102-ld-hd-urdf.zip) | ✅ 源码与 ZIP 已提供<br>🟡 joint5 固定定义、HD 动力学参数及运行待验证 |

## 物料清单

下表列出 102-HD 的 **31 项装机物料**；无图片的条目标为待补。

打印件名称与 STEP、STL 及独立 3MF 文件名一致。备注中的打印参数仅供参考，尚未完成实物打印验证。

| 序号 | 名称 | 图片 | 描述 | 数量 | 备注 |
| :---: | --- | :---: | --- | :---: | --- |
| 1 | RP8-U45H-M | 待补 | RP8-U45H-M，固件版本V225 | 4 | 装机件 |
| 2 | RP8-U45H-M-C028 | 待补 | RP8-U45H-M-C028，半成品， 换单轴后盖，固件版本V225 | 2 | 装机件 |
| 3 | RP8-U45H-M-C029 | 待补 | RP8-U45H-M-C029，半成品，D轴，换单轴后盖，固件版本V225 | 1 | 装机件 |
| 4 | star-arm-102-base-bottom | star-arm-102-base-bottom | PLA 3D 打印件（象牙白） | 1 | 壁数 2；填充 15% |
| 5 | star-arm-102-base-top | star-arm-102-base-top | PLA 3D 打印件（象牙白） | 1 | 分区域参数，详见 3MF |
| 6 | star-arm-102-link1 | star-arm-102-link1 | PLA 3D 打印件（象牙白） | 1 | 壁数 5；填充 50% |
| 7 | star-arm-102-link2 | star-arm-102-link2 | PLA 3D 打印件（象牙白） | 1 | 壁数 2；填充 10% |
| 8 | star-arm-102-link3 | star-arm-102-link3 | PLA 3D 打印件（象牙白＋黑色） | 1 | 分区域参数，详见 3MF |
| 9 | star-arm-102-link4 | star-arm-102-link4 | PLA 3D 打印件（象牙白） | 1 | 壁数 2；填充 15% |
| 10 | star-arm-102-link5 | star-arm-102-link5 | PLA 3D 打印件（象牙白） | 1 | 壁数 2；填充 15% |
| 11 | star-arm-102-link6-handle | star-arm-102-link6-handle | PLA 3D 打印件（象牙白） | 1 | 壁数 5；填充 15% |
| 12 | star-arm-102-handle | star-arm-102-handle | PLA 3D 打印件（象牙白） | 1 | 壁数 2；填充 15% |
| 13 | star-arm-102-finger-ring-left | star-arm-102-finger-ring-left | PLA 3D 打印件（象牙白） | 1 | 壁数 2；填充 15% |
| 14 | star-arm-102-finger-ring-right | star-arm-102-finger-ring-right | PLA 3D 打印件（象牙白） | 1 | 壁数 2；填充 15% |
| 15 | hd-button-cover | hd-button-cover | PLA 3D 打印件（象牙白） | 1 | 壁数 2；填充 15% |
| 16 | hd-button-base | hd-button-base | PLA 3D 打印件（象牙白） | 1 | 壁数 2；填充 15% |
| 17 | PCBA | UC-01 | UC-01 XT30接口 | 1 | 装机件 |
| 18 | PCBA | 待补 | UK-01带座子 | 1 | 装机件 |
| 19 | 滚针轴承 | 待补 | AXK2035+2AS | 1 | 装机件 |
| 20 | 线材 | 待补 | PH-3Y 双头反向60芯 0.08 黑色硅胶排线L=120 mm  黑色编织线 | 6 | 装机件 |
| 21 | 线材 | 待补 | PH-3Y 双头反向60芯 0.08 黑色硅胶排线L=200 mm  黑色编织线 | 2 | 装机件 |
| 22 | 螺丝 | 待补 | HSCS M3*10 12.9级内六角圆柱头螺钉 | 1 | 装机件 |
| 23 | 螺丝 | 待补 | M3*22黑色内六角 | 4 | 装机件 |
| 24 | 螺丝 | 待补 | M3*10加硬包黑十字槽螺杆 | 1 | 装机件 |
| 25 | 螺丝 | 待补 | PB2.0*5 自攻十字槽加硬包黑沉头螺杆 | 46 | 装机件 |
| 26 | 螺丝 | 待补 | M2*4.5 预点胶十字槽螺杆黑色沉头 | 35 | 装机件 |
| 27 | 螺丝 | 待补 | M2*10 黑色内六角 | 8 | 装机件 |
| 28 | 螺丝 | 待补 | M2*8 黑色内六角 | 8 | 装机件 |
| 29 | 螺丝 | 待补 | M3*12自攻十字槽螺杆 | 2 | 装机件 |
| 30 | 螺母 | 待补 | M3防松螺母 黑色 | 5 | 装机件 |
| 31 | 垫片 | 待补 | M3不锈钢 | 1 | 装机件 |

发现资料错误或需要帮助？请通过 [Support 支持中心](https://fashionstar.com.hk/support/) 联系我们，并注明型号及对应文件或条目。

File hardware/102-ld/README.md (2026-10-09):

# Star Arm 102-LD hardware

[← Hardware Resources](../README.md)　|　<sub>**English** / [简体中文](README.zh.md)</sub>

<p align="center">
  <a href="https://fashionstar.com.hk/store/wp-content/uploads/2026/09/102-ld-diy-kit-main-image-01-2.webp">Star Arm 102-LD DIY kit</a>
  <a href="https://fashionstar.com.hk/store/wp-content/uploads/2026/04/102-ld-main-image-02.webp">Star Arm 102-LD product view 2</a>
  <a href="https://fashionstar.com.hk/store/wp-content/uploads/2026/04/102-ld-main-image-03.webp">Star Arm 102-LD product view 3</a>
  <a href="https://fashionstar.com.hk/store/wp-content/uploads/2026/04/102-ld-main-image-04.webp">Star Arm 102-LD product view 4</a>
  <a href="https://fashionstar.com.hk/store/wp-content/uploads/2026/04/102-ld-main-image-05.webp">Star Arm 102-LD product view 5</a>
  <a href="https://fashionstar.com.hk/store/wp-content/uploads/2026/04/102-ld-main-image-06.webp">Star Arm 102-LD product view 6</a>
</p>

**On this page:**

- [📂 Resources](#resources)
- [📋 Bill of Materials](#bill-of-materials)

## Resources

| Directory | Description | Status |
| --- | --- | --- |
| [assembly-guide/](assembly-guide/README.md) | Main arm assembly video | ✅ Video available<br>🟡 Revision and wiring coverage under review |
| [step/](step/) | Part models in parts/; shared assembly in assembly/ | ✅ Files available<br>🟡 Revision alignment under review |
| [printing/](printing/) | 3MF projects; STL: [View parts](printing/stl/) · [Download ZIP](printing/stl/star-arm-102-ld-stl.zip) | ✅ 11 individual 3MF files and combined project available; 11 STL files and ZIP available<br>🟡 Print validation pending |
| [drawings/](drawings/) | PDF / DWG drawings | ✅ Reference files available<br>🟡 Revision under review |
| [robot-description/](robot-description/) | ROS 1 package: [Browse source](robot-description/) · [Download ZIP](robot-description/star-arm-102-ld-hd-urdf.zip) | ✅ Source and ZIP available<br>🟡 Fixed joint5 definition, HD dynamics and runtime pending validation |

## Bill of Materials

The table below lists **28 assembly items** for 102-LD. Missing images are marked pending.

Printed-part names match the STEP, STL, and individual 3MF filenames. Print settings in Notes are references pending physical print validation.

| No. | Name | Image | Description | Quantity | Notes |
| :---: | --- | :---: | --- | :---: | --- |
| 1 | RA8-U01H-M | Pending | Light lubrication; firmware V225 | 4 | Installed part |
| 2 | RA8-U02H-M | Pending | Light lubrication; D-shaft, single-shaft rear cover; firmware V225 | 1 | Installed part |
| 3 | RA8-U03H-M | Pending | Light lubrication; single-shaft rear cover; firmware V225 | 2 | Installed part |
| 4 | star-arm-102-base-bottom | star-arm-102-base-bottom | PLA 3D printed part (ivory) | 1 | 2 wall loops; 15% infill |
| 5 | star-arm-102-base-top | star-arm-102-base-top | PLA 3D printed part (ivory) | 1 | Settings vary by region; see 3MF |
| 6 | star-arm-102-link1 | star-arm-102-link1 | PLA 3D printed part (ivory) | 1 | 5 wall loops; 50% infill |
| 7 | star-arm-102-link2 | star-arm-102-link2 | PLA 3D printed part (ivory) | 1 | 2 wall loops; 10% infill |
| 8 | star-arm-102-link3 | star-arm-102-link3 | PLA 3D printed part (ivory + black) | 1 | Settings vary by region; see 3MF |
| 9 | star-arm-102-link4 | star-arm-102-link4 | PLA 3D printed part (ivory) | 1 | 2 wall loops; 15% infill |
| 10 | star-arm-102-link5 | star-arm-102-link5 | PLA 3D printed part (ivory) | 1 | 2 wall loops; 15% infill |
| 11 | star-arm-102-link6-handle | star-arm-102-link6-handle | PLA 3D printed part (ivory) | 1 | 5 wall loops; 15% infill |
| 12 | star-arm-102-handle | star-arm-102-handle | PLA 3D printed part (ivory) | 1 | 2 wall loops; 15% infill |
| 13 | star-arm-102-finger-ring-left | star-arm-102-finger-ring-left | PLA 3D printed part (ivory) | 1 | 2 wall loops; 15% infill |
| 14 | star-arm-102-finger-ring-right | star-arm-102-finger-ring-right | PLA 3D printed part (ivory) | 1 | 2 wall loops; 15% infill |
| 15 | Thrust needle roller bearing | Pending | AXK2035 + 2AS | 1 | Installed part |
| 16 | UC-01 board | UC-01 | DC power lead: 0.75 mm², 5.5 × 2.1 mm female, 0.15 m | 1 | Installed part |
| 17 | 120 mm servo cable | Pending | PH-3Y, reverse-wired ends, black braided silicone cable | 5 | Installed part |
| 18 | 200 mm servo cable | Pending | PH-3Y, reverse-wired ends, black braided silicone cable | 2 | Installed part |
| 19 | M3 × 10 socket-head screw | Pending | HSCS, grade 12.9 | 1 | Installed part |
| 20 | M3 × 22 socket-head screw | Pending | Black finish | 4 | Installed part |
| 21 | M3 × 10 Phillips screw | Pending | Hardened, black finish | 1 | Installed part |
| 22 | PB2.0 × 5 self-tapping screw | Pending | Phillips countersunk, hardened, black finish | 39 | Installed part |
| 23 | M2 × 4.5 Phillips screw | Pending | Countersunk, black finish, pre-applied threadlocker | 35 | Installed part |
| 24 | M2 × 8 socket-head screw | Pending | Black finish | 16 | Installed part |
| 25 | M2 × 10 socket-head screw | Pending | Black finish | 8 | Installed part |
| 26 | M3 × 12 self-tapping screw | Pending | Phillips head | 2 | Installed part |
| 27 | M3 locknut | Pending | Black finish | 5 | Installed part |
| 28 | M3 washer | Pending | Stainless steel | 1 | Installed part |

Found an error in these resources or need help? Contact our [Support Hub](https://fashionstar.com.hk/support/) with your model and the relevant file or item.

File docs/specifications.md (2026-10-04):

# Product overview and joint mapping

[Home](../README.md) · [Hardware setup](hardware-setup.md)

Star Arm 102 provides six arm joints and a gripper/handle channel. LD and HD are leaders; FL is the actuated follower. HD is the pose-holding leader, using high-torque RP8 coreless servos for stable demonstrations and extended data collection. Its button behavior depends on the software integration.

| Model | Role | Next step |
| --- | --- | --- |
| 102-LD | Leader for teleoperation | [Python](../python-sdk/README.md) or [release-compatible LeRobot](../lerobot/README.md) |
| 102-HD | Leader with button-board support | [Python](../python-sdk/README.md) or [refactored LeRobot](../lerobot/lerobot-stararm102/README.md) |
| 102-FL | Follower for teleoperation and policy execution | [ACT model](../lerobot/examples/act_pick/README.md) or [ROS 2](../ros2-humble/README.md) |

## Joint IDs and names

| Servo ID | Release-compatible LeRobot | Refactored LeRobot | ROS description |
| --- | --- | --- | --- |
| 0 | `Motor_0` | `shoulder_pan` | `joint1` |
| 1 | `Motor_1` | `shoulder_lift` | `joint2` |
| 2 | `Motor_2` | `elbow_flex` | `joint3` |
| 3 | `Motor_3` | `wrist_flex` | `joint4` |
| 4 | `Motor_4` | `wrist_yaw` | `joint5` |
| 5 | `Motor_5` | `wrist_roll` | `joint6` |
| 6 | `gripper` | `gripper` | `joint7_left` (with a mimicked right finger) |
| 7, when fitted | Not part of the seven action channels | HD button board | Not an arm joint |

Matching IDs do not mean matching units, signs, scaling, or calibration. See [plugin compatibility](compatibility.md). Do not transfer joint values between these interfaces without the appropriate conversion.

For product dimensions, payload, and the exact supplied configuration, use the official [LD](https://fashionstar.com.hk/store/product/star-arm-102-ld/), [HD](https://fashionstar.com.hk/store/product/star-arm-102-hd/), and [FL](https://fashionstar.com.hk/store/product/star-arm-102-fl/) specifications. The [LD engineering drawings](../hardware/102-ld/drawings/) provide mechanical reference files. Motion limits in a URDF or configuration describe that software model and are not a substitute for the limits of your hardware revision.

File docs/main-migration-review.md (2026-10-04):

# Main migration review — October 3, 2026

## Decision and scope

The phase-one branch can replace the current main entry by a fast-forward update. This is a repository coverage and software/documentation review, not a completed hardware qualification. The previous main commit remains in Git history.

## Coverage

The previous main contained 201 tracked files. Before the final repairs, 174 had byte-identical content retained somewhere in the phase-one branch, including renamed resources. The review restored two omitted `.gitignore` files, bringing that count to 176. The remaining 25 files are documentation, the root ignore rules, the direct Python entry, and ROS description packaging/paths reviewed for their purpose rather than byte identity.

- Original hardware CAD, drawings, BOM, media, simulation meshes, plugin implementations, and other source assets remain available under their new paths.
- Current documentation replaces conflicting older commands. Longer Chinese instructions remain in labeled historical guides, while eight current bilingual README pairs have matching structure and resources.
- Original store, website, video, and resource URLs remain represented. The obsolete uppercase LeRobot link now uses the current local path; the unsupported repository-wide MIT badge was removed in favor of component license scope.
- Direct Python control retains its leader/follower behavior and legacy leader flag, with explicit port selection and argument validation added.
- The URDF retains its original joint definitions, limits, transforms, and dynamics. Mesh filenames and installation paths changed; ROS launch defaults follow the new URDF filename.
- Restored the refactored LeRobot guide's own-checkpoint evaluation path with matching recording/training camera names and output paths. It remains an unvalidated hardware example.

## Validation

- 103 Markdown documents: local file/image links pass.
- Eight bilingual README pairs: section, table, image, command, and link-target checks pass. Translation meaning was manually reviewed.
- Seven mocked Python entry tests pass; no hardware connected.
- Python source parsing and refactored LeRobot shell syntax pass.
- URDF semantic comparison against previous main passes after normalizing mesh filenames.
- ROS description resource installation and all installed mesh references pass. This is not a full ROS/colcon/runtime test.
- 32 imported handoff files were hash-checked against their sources before the phase-one publication; exported CAD files preserve their original bytes.

## Remaining work

See [hardware resources](../hardware/README.md), [cross-brand capabilities](../integrations/compatibility.md), and [runtime validation](validation.md).

Outstanding items include standalone printing STL, approved model-specific URDFs, complete assembly instructions/video, production-version reconciliation, BOM/print-setting conflicts, cross-brand setup packages and physical validation, and partner application end-to-end validation. Their status must remain visible until evidence is supplied.

## Migration effects

Top-level resource paths use lowercase and hyphens. Old external links to uppercase paths and removed duplicate README aliases may break on GitHub; update external documentation to the current URLs. Historical commits retain their original paths. Python import/package identifiers remain unchanged. The repository's workflow runs on main pushes and pull requests; workflow completion is separate from pushing the branch.

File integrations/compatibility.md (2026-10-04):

# Cross-Brand Compatibility and Evidence

[Pairing directory](README.md) · [Software environments](../docs/compatibility.md)

Status reviewed: October 3, 2026. **Pending** means this repository does not yet provide sufficient pairing-specific instructions or test evidence; it does not mean the pairing is impossible. **Upstream documented** means an external guide exists, not that this documentation update bench-tested the hardware.

| Follower | LD leader | HD leader / button behavior | Direct Python | LeRobot teleoperation | Data collection | Training / inference |
| --- | --- | --- | --- | --- | --- | --- |
| [Galaxea A1](galaxea-a1/README.md) | Pending | Pending / pending | Pending | Pending | Pending | Pending |
| [Lumos Touch](lumos-touch/README.md) | Pending | Pending / pending | Pending | Pending | Pending | Pending |
| [YAM, model pending](yam/README.md) | Pending | Pending / pending | Pending | Pending | Pending | Pending |
| [Seeed reBot B601-DM / B601-RS](seeed-rebot/README.md) | Confirm exact 102 leader revision against upstream | Exact HD revision and buttons pending | No dedicated example here | Upstream documented | Upstream documented | No pairing-specific validated policy here |

The reBot row refers to the [upstream LeRobot main-branch guide for B601-DM and B601-RS](https://huggingface.co/docs/lerobot/main/rebot_b601), reviewed on October 4, 2026. Follow its source-install instructions and select the matching motor family and adapter. Its leader is named StarArm102 / reBot Arm 102; this is not blanket confirmation for every LD or HD revision. DM and RS configurations must be validated separately.

## Evidence needed for a validated entry

Record the exact follower and leader revisions; firmware, SDK and plugin versions or commits; operating system and Python version; adapters and wiring; calibration procedure; joint or Cartesian mapping; gripper behavior; HD button behavior where applicable; and test date and results.

Validate communication, teleoperation, data recording, training, and inference separately. A demo video alone does not specify a reproducible environment. A virtual model following a leader does not establish real-follower control. Galaxea A1 and A1Z must be tracked separately.

The supplied Star Arm 102-FL ACT policy is not a cross-brand pretrained policy. Different action spaces, kinematics, calibration, grippers, or cameras require their own integration and evaluation.

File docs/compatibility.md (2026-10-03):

# Versions and compatibility

For third-party follower setups, see [cross-brand pairing resources](../integrations/compatibility.md).

[Home](../README.md) · [LeRobot setup](../lerobot/README.md)

## Choose an environment

| Path | Hardware / purpose | Environment | Evidence and limits |
| --- | --- | --- | --- |
| Direct Python | LD/HD → FL; basic communication | Ubuntu 22.04; `pyserial`, `fashionstar-uart-sdk` | Existing script supports these modes. This phase checks CLI behavior; physical direction, zero pose, and HD board behavior still need a bench test. |
| Released ACT example | FL + `up` and `front` cameras; optional leader for resets | Python 3.10; LeRobot 0.4.1; both StarArm plugins 0.0.1 | Environment and demo video recorded in the existing `act-pick-v1.0.0` release guide. New customer setups still require validation. |
| Refactored HD/FL | HD/LD input and FL control | Separate environment; source package in `lerobot/lerobot-stararm102/` | Package declares LeRobot >=0.4, UART SDK >=1.3.12, motor plugin >=0.0.6. These are dependency bounds, not proof every newer version works. |
| ROS 2 | FL integration, RViz/MoveIt/Gazebo | Ubuntu 22.04, ROS 2 Humble | Existing launch files; no new ROS build or hardware validation claimed by the English documentation update. |
| reBot | 102 leader + B601 follower | Follow the upstream reBot guide in a separate environment | Upstream device names and versions differ from older Fashion Star fork examples. HD button support must be checked separately. |

## Do not mix the two LeRobot plugin generations

| Detail | Release-compatible plugins | Refactored package |
| --- | --- | --- |
| Source directories | `lerobot-robot-stararm102/` and `lerobot-teleoperator-stararm102/` | `lerobot-stararm102/` |
| Follower type | `lerobot_robot_stararm102` | `stararm102_fl` |
| Leader type | `lerobot_teleoperator_stararm102` | `stararm102_hd` |
| Joint features | `Motor_0.pos` … `Motor_5.pos`, `gripper.pos` | `shoulder_pan.pos` … `wrist_roll.pos`, `gripper.pos` |
| Position representation | Normalized ranges by default; configurable degree mode for body joints | Degree-based values with configured direction/scaling |
| Supplied ACT model | Use this path | Not a drop-in replacement for the released model |

Both leader implementations use the distribution/import name `lerobot_teleoperator_stararm102`. Installing one can replace the other. Use different environments; do not solve a mismatch by renaming action keys or reusing another integration's calibration file.

The refactored package also exports its FL robot through that package. CLI discovery was checked with LeRobot 0.4.1 after a regular install. A default editable install could be imported by Python but was missed by CLI discovery; follow the regular installation command in the guide.

## Record your working setup

Before upgrading a working installation:

```bash
python --version
python -m pip freeze > stararm102-environment.txt
git rev-parse HEAD
```

Record the arm model/revision, firmware identification if available, button board mode, calibration device IDs, camera models and names, and GPU/driver details. No single firmware version is specified for all hardware revisions in this repository; do not flash an unrelated image to match a tutorial.

The ACT release's original guide reports an RTX 5070 Ti with PyTorch 2.7.1, torchvision 0.22.1, torchaudio 2.7.1, CUDA 12.8 wheels. This is a recorded configuration, not a guarantee for other GPUs. Installation details are maintained in the [ACT guide](../lerobot/examples/act_pick/inference.md).

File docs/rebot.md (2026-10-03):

# Star Arm 102 + reBot: guide moved

The current guide is now under [integrations/seeed-rebot](../integrations/seeed-rebot/README.md), alongside the other cross-brand pairings.

[Open the reBot guide](../integrations/seeed-rebot/README.md) · [All follower pairings](../integrations/README.md) · [Software environments](compatibility.md)

This page remains to preserve existing links.

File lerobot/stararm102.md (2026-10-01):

> 历史中文补充教程：当前安装与两代插件的选择请从 [LeRobot 入口](README.md) 开始。

# 如何搭建具身智能LeRobot-starai系列机械臂并完成自定义抓取任务

## 产品介绍

1. **开源 & 便于二次开发**
   本系列舵机由[华馨京科技](https://fashionrobo.com/)提供，是一套开源、便于二次开发的6+1自由度机器臂解决方案。
2. **支持 LeRobot 平台集成**
   专为与 [LeRobot 平台](https://github.com/huggingface/lerobot) 集成而设计。该平台提供 PyTorch 模型、数据集与工具，面向现实机器人任务的模仿学习（包括数据采集、仿真、训练与部署）。
3. **丰富的学习资源**
   提供全面的开源学习资源，包括环境搭建，安装与调试与自定义夹取任务案例帮助用户快速上手并开发机器人应用。
4. **兼容 Nvidia 平台**
   支持通过 reComputer Mini J4012 Orin NX 16GB 平台进行部署。

## 特点内容

- **零组装**:  即刻上手｜一开箱即踏入AI时代。
- 6+1自由度结构设计，420mm臂展，赋予无限操作可能。
- 智能平行夹爪，最大开合66mm，模块化指尖，精准抓取不设限。

## 初始环境搭建

For Ubuntu X86:

- Ubuntu 22.04
- CUDA 12+
- Python 3.10
- Torch 2.6

## 安装与调试

### 安装LeRobot

需要根据你的 CUDA 版本安装 pytorch 和 torchvision 等环境。

1. 安装 Miniconda： 对于 Jetson：

    ```bash
    wget https://repo.anaconda.com/miniconda/Miniconda3-latest-Linux-aarch64.sh
    chmod +x Miniconda3-latest-Linux-aarch64.sh
    ./Miniconda3-latest-Linux-aarch64.sh
    source ~/.bashrc
    ```

    或者，对于 X86 Ubuntu 22.04：

    ```bash
    mkdir -p ~/miniconda3
    cd miniconda3
    wget https://repo.anaconda.com/miniconda/Miniconda3-latest-Linux-x86_64.sh -O ~/miniconda3/miniconda.sh
    bash ~/miniconda3/miniconda.sh -b -u -p ~/miniconda3
    rm ~/miniconda3/miniconda.sh
    source ~/miniconda3/bin/activate
    conda init --all
    ```

2. 创建并激活一个新的 conda 环境用于 LeRobot

    ```bash
    conda create -y -n lerobot python=3.10 && conda activate lerobot
    ```

3. 克隆 LeRobot 仓库：

    ```bash
    git clone https://github.com/servodevelop/lerobot.git
    ```

4. 使用 miniconda 时，在环境中安装 ffmpeg：

    ```bash
    conda install ffmpeg -c conda-forge
    ```

    这通常会为你的平台安装使用 libsvtav1 编码器编译的 ffmpeg 7.X。如果不支持 libsvtav1（可以通过 ffmpeg -encoders 查看支持的编码器），你可以：

    - 【适用于所有平台】显式安装 ffmpeg 7.X：

    ```bash
    conda install ffmpeg=7.1.1 -c conda-forge
    ```

5. 安装LeRobot：

    ```bash
    cd ~/lerobot && pip install -e .
    ```

    对于 Jetson Jetpack 设备（请确保在执行此步骤前按照[此链接教程](https://github.com/Seeed-Projects/reComputer-Jetson-for-Beginners/tree/main/3-Basic-Tools-and-Getting-Started/3.5-Pytorch)第 5 步安装了 Pytorch-gpu 和 Torchvision）：

    ```bash
    conda install -y -c conda-forge "opencv>=4.10.0.84"  # 通过 conda 安装 OpenCV 和其他依赖，仅适用于 Jetson Jetpack 6.0+
    conda remove opencv   # 卸载 OpenCV
    pip3 install opencv-python==4.10.0.84  # 使用 pip3 安装指定版本 OpenCV
    conda install -y -c conda-forge ffmpeg
    conda uninstall numpy
    pip3 install numpy==1.26.0  # 该版本需与 torchvision 兼容
    ```

6. 安装Fashionstar电机依赖：

    ```bash
    pip install lerobot_teleoperator_stararm102   #使用 pip 安装StarArm102_leader
    pip install lerobot_robot_stararm102    #使用 pip 安装StarArm102_follower
    ```

7. 检查 Pytorch 和 Torchvision

    由于通过 pip 安装 LeRobot 环境时会卸载原有的 Pytorch 和 Torchvision 并安装 CPU 版本，因此需要在 Python 中进行检查。

    ```python
    import torch
    print(torch.cuda.is_available())
    ```

    如果输出结果为 False，需要根据[官网教程](https://pytorch.org/index.html)重新安装 Pytorch 和 Torchvision。

### 接线

https://github.com/user-attachments/assets/56130bd9-21ee-4ae4-9cac-3817ac4d659f

### 手臂端口设置

在终端输入以下指令来找到两个机械臂对应的端口号：

```bash
lerobot-find-port
```

例如：

1. 识别Leader时端口的示例输出（例如，在 Mac 上为 `/dev/tty.usbmodem575E0031751`，或在 Linux 上可能为 `/dev/ttyUSB0`）
2. 识别Follower时端口的示例输出（例如，在 Mac 上为 `/dev/tty.usbmodem575E0032081`，或在 Linux 上可能为 `/dev/ttyUSB1`）

> [!NOTE]
>
> 如果识别不到ttyUSB0串口信息。尝试以下方法。
>
> 列出所有usb口。
>
> ```sh
> lsusb
> ```
>
> 
>
> 识别成功，查看ttyusb的信息
>
> ```sh
> sudo dmesg | grep ttyUSB
> ```
>
> 
>
> 最后一行显示断连，因为brltty在占用该USB设备号，移除掉就可以了
>
> ```sh
> sudo apt remove brltty
> ```
>
> 
>
> 最后，赋予权限
>
> ```sh
> sudo chmod 777 /dev/ttyUSB*
> ```
>

## 校准

如果是第一次校准，请对每个关节左右转动到极限位置。

如果是重新校准，按照命令提示输入字母c后按Enter键。

下面是参考值,通常情况下，真实的限位参考值的±10°范围内。

| 舵机ID  | 角度下限参考值 | 角度上限参考值 | 备注 |
| --- | ---: | ---: | --- |
| motor_0 | -180° | 180° | 转动到限位处 |
| motor_1 | -90° | 90° | 转动到限位处 |
| motor_2 | -90° | 90° | 转动到限位处 |
| motor_3 | -180° | 180° | 没有限位，需转动到角度上下限参考值 |
| motor_4 | -90° | 90° | 转动到限位处 |
| motor_5 | -180° | 180° | 没有限位，需转动到角度上下限参考值 |
| motor_6 | 0° | 100° | 转动到限位处 |

### leader

> [!TIP]
>
> 将leader连接到/dev/ttyUSB0，或者修改下面的命令。

```bash
lerobot-calibrate     --teleop.type=lerobot_teleoperator_stararm102 --teleop.port=/dev/ttyUSB0 --teleop.id=my_awesome_stararm102_leader_arm
```

### follower

> [!TIP]
>
> 将follower连接到/dev/ttyUSB1，或者修改下面的命令。

```bash
lerobot-calibrate     --robot.type=lerobot_robot_stararm102 --robot.port=/dev/ttyUSB1 --robot.id=my_awesome_stararm102_follower_arm
```

## 遥操作

https://github.com/user-attachments/assets/23b3aa00-9889-48d3-ae2c-00ad50595e0a

您已准备好遥操作您的机器人（不包括摄像头）！运行以下简单脚本：

```bash
lerobot-teleoperate \
    --robot.type=lerobot_robot_stararm102 \
    --robot.port=/dev/ttyUSB1 \
    --robot.id=my_awesome_stararm102_follower_arm \
    --teleop.type=lerobot_teleoperator_stararm102 \
    --teleop.port=/dev/ttyUSB0 \
    --teleop.id=my_awesome_stararm102_leader_arm
```

远程操作命令将自动检测下列参数:

1. 识别任何缺失的校准并启动校准程序。
2. 连接机器人和远程操作设备并开始远程操作。

程序启动后，悬停按钮依旧生效。

## 添加摄像头

https://github.com/user-attachments/assets/82650b56-96be-4151-9260-2ed6ab8b133f

在插入您的两个 USB 摄像头后，运行以下脚本以检查摄像头的端口号，切记摄像头避免插在USB Hub上，USB Hub速率太慢会导致读不到图像数据。

```bash
lerobot-find-cameras opencv # or realsense for Intel Realsense cameras
```

终端将打印出以下信息。以我的笔记本为例，笔记本摄像头为Camera0和Camera1，index_or_path分别为2和4。

```markdown
--- Detected Cameras ---
Camera #0:
  Name: OpenCV Camera @ /dev/video2
  Type: OpenCV
  Id: /dev/video2
  Backend api: V4L2
  Default stream profile:
    Format: 0.0
    Width: 640
    Height: 480
    Fps: 30.0
--------------------
Camera #1:
  Name: OpenCV Camera @ /dev/video4
  Type: OpenCV
  Id: /dev/video4
  Backend api: V4L2
  Default stream profile:
    Format: 0.0
    Width: 640
    Height: 360
    Fps: 30.0
--------------------

Finalizing image saving...
Image capture finished. Images saved to outputs/captured_images
```

确认外接摄像头后，将摄像头信息替换下方cameras信息您将能够在遥操作时在计算机上显示摄像头：

```bash
lerobot-teleoperate \
    --robot.type=lerobot_robot_stararm102 \
    --robot.port=/dev/ttyUSB1 \
    --robot.id=my_awesome_stararm102_follower_arm \
    --robot.cameras="{ front: {type: opencv, index_or_path: 2, width: 640, height: 480, fps: 30}}" \
    --teleop.type=lerobot_teleoperator_stararm102 \
    --teleop.port=/dev/ttyUSB0 \
    --teleop.id=my_awesome_stararm102_leader_arm \
    --display_data=true
# new
# lerobot-teleoperate \
#     --robot.type=lerobot_robot_stararm102 \
#     --robot.port=/dev/ttyUSB1 \
#     --robot.id=my_awesome_stararm102_follower_arm \
#     --robot.cameras="{ front: {type: opencv, index_or_path: 2, width: 640, height: 480, fps: 30, fourcc: "MJPG"}}" \
#     --teleop.type=lerobot_teleoperator_stararm102 \
#     --teleop.port=/dev/ttyUSB0 \
#     --teleop.id=my_awesome_stararm102_leader_arm \
#     --display_data=true
```

## 数据集制作采集

https://github.com/user-attachments/assets/8bb25714-783a-4f29-83dd-58b457aed80c

> [!TIP]
>
> 如果您想使用 Hugging Face Hub 的功能来上传您的数据集，请参考以下官方文章链接。本教程将不涉及这部分内容。
>
> [lmitation Learning for Robots](https://huggingface.co/docs/lerobot/il_robots?teleoperate_koch_camera=Command)
>
>

一旦您熟悉了遥操作，您就可以开始您的第一个数据集。

记录 10 个回合：

```bash
lerobot-record \
    --robot.type=lerobot_robot_stararm102 \
    --robot.port=/dev/ttyUSB1 \
    --robot.id=my_awesome_stararm102_follower_arm \
    --robot.cameras="{ up: {type: opencv, index_or_path: /dev/video2, width: 640, height: 480, fps: 30},front: {type: opencv, index_or_path: /dev/video4, width: 640, height: 480, fps: 30}}" \
    --teleop.type=lerobot_teleoperator_stararm102 \
    --teleop.port=/dev/ttyUSB0 \
    --teleop.id=my_awesome_stararm102_leader_arm \
    --display_data=true \
    --dataset.repo_id=starai/record-test \
    --dataset.episode_time_s=30 \
    --dataset.reset_time_s=30 \
    --dataset.num_episodes=10 \
    --dataset.push_to_hub=False \
    --dataset.single_task="Grab the black cube"
```

### 记录功能

- record提供了一套用于在机器人操作过程中捕获和管理数据的工具:

#### 1.数据存储

- 数据使用 `LeRobotDataset` 格式存储，并在录制过程中存储在磁盘上。

#### 2.检查点和恢复

- 记录期间会自动创建检查点。
- 如果出现问题，可以通过使用 重新运行相同的命令来恢复。恢复录制时，必须设置为**要录制的额外剧集数**，而不是数据集中的目标总剧集数！`--resume=true` `--dataset.num_episodes`
- 要从头开始录制，请**手动删除**数据集目录。

#### 3.记录参数

使用命令行参数设置数据记录流：

--dataset.episode_time_s=60每个数据记录插曲的持续时间(默认值:60秒)。
--dataset.reset_time_s=60每集后重置环境的持续时间(默认:60秒)。
--dataset.num_episodes=50记录的总集数(默认值:50秒)。

#### 4.录制期间的键盘控制

使用键盘快捷键控制数据记录流：

- 按**右方向键(→)** ： 提前停止当前情节或重置时间,然后移动到下一个。
- 按**左方向键(←)** ：取消当前插曲并重新录制。
- 按**ESC**：立即停止会话,编码视频并上传数据集。

>[!TIP]
>
>在 Linux 上,如果左右箭头键和转义键在数据记录过程中没有任何效果,请确保已设置$DISPLAY环境变量。参见 pynput 限制。
>
>一旦你熟悉了数据记录,你就可以创建一个更大的数据集进行训练。一个好的开始任务是抓住一个物体在不同的位置,并把它放在一个垃圾箱。我们建议录制至少50集,每个地点10集。保持相机固定,并在整个录音中保持一致的抓握行为。还要确保你操纵的对象在相机上可见。一个好的经验法则是,你应该能够只看相机图像自己完成任务。

## 重播一个回合

播放已经录制好的动作，可以借此测试机器人动作的重复性。

```bash
lerobot-replay \
    --robot.type=lerobot_robot_stararm102 \
    --robot.port=/dev/ttyUSB1 \
    --robot.id=my_awesome_stararm102_follower_arm \
    --dataset.repo_id=starai/record-test \
    --dataset.episode=1 # choose the episode you want to replay
```

## 训练

要训练一个控制您机器人策略，以下是一个示例命令：

```bash
lerobot-train \
  --dataset.repo_id=starai/record-test \
  --policy.type=act \
  --output_dir=outputs/train/act_stararm102_test \
  --job_name=act_stararm102_test \
  --policy.device=cuda \
  --wandb.enable=False \
  --policy.repo_id=starai/my_policy
```

1. 我们提供了数据集作为参数。`dataset.repo_id=starai/record-test`
2. 我们为 .这将从 [`configuration_act.py`](https://github.com/huggingface/lerobot/blob/main/src/lerobot/policies/act/configuration_act.py) 加载配置。重要的是，此策略将自动适应机器人的电机状态、电机动作和相机的数量已保存在您的数据集中。`policy.type=act` `laptop` `phone`
3. 我们提供了使用[权重和偏差](https://docs.wandb.ai/quickstart)来可视化训练图。这是可选的，但如果您使用它，请确保您已通过运行 登录。`wandb.enable=true` `wandb login`

要从某个检查点恢复训练。

```bash
lerobot-train \
  --config_path=outputs/train/act_stararm102_test/checkpoints/last/pretrained_model/train_config.json \
  --resume=true
```

## 运行推理并评估

运行以下命令记录 10 个评估回合：

```bash
lerobot-record  \
  --robot.type=lerobot_robot_stararm102 \
  --robot.port=/dev/ttyUSB1 \
  --robot.cameras="{ up: {type: opencv, index_or_path: /dev/video2, width: 640, height: 480, fps: 30},front: {type: opencv, index_or_path: /dev/video4, width: 640, height: 480, fps: 30}}" \
  --robot.id=my_awesome_stararm102_follower_arm \
  --display_data=false \
  --dataset.repo_id=starai/eval_record-test \
  --dataset.single_task="Put lego brick into the transparent box" \
  --policy.path=outputs/train/act_stararm102_test/checkpoints/last/pretrained_model
  # <- Teleop optional if you want to teleoperate in between episodes \
  # --teleop.type=lerobot_teleoperator_stararm102 \
  # --teleop.port=/dev/ttyUSB0 \
  # --teleop.id=my_awesome_stararm102_leader_arm \
```

## FAQ

- 如果使用本文档教程，请git clone本文档推荐的github仓库`https://github.com/servodevelop/lerobot.git`。

- 如果遥操作正常，而带Camera的遥操作无法显示图像界面，请参考[这里](https://github.com/huggingface/lerobot/pull/757/files)

- 如果在数据集遥操作过程中出现libtiff的问题，请更新libtiff版本。

  ```bash
  conda install libtiff==4.5.0  #for Ubuntu 22.04 is libtiff==4.5.1
  ```

- 执行完安装LeRobot可能会自动卸载gpu版本的pytorch，所以需要在手动安装torch-gpu。

- 对于Jetson，请先安装[Pytorch和Torchvsion](https://github.com/Seeed-Projects/reComputer-Jetson-for-Beginners/blob/main/3-Basic-Tools-and-Getting-Started/3.3-Pytorch-and-Tensorflow/README.md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)再执行`conda install -y -c conda-forge ffmpeg`,否则编译torchvision的时候会出现ffmpeg版本不匹配的问题。

- 在3060的8G笔记本上训练ACT的50组数据的时间大概为6小时，在4090和A100的电脑上训练50组数据时间大概为2~3小时。

- 数据采集过程中要确保摄像头位置和角度和环境光线的稳定，并且减少摄像头采集到过多的不稳定背景和行人，否则部署的环境变化过大会导致机械臂无法正常抓取。

- 数据采集命令的num-episodes要确保采集数据足够，不可中途手动暂停，因为在数据采集结束后才会计算数据的均值和方差，这在训练中是必要的数据。

- 如果程序提示无法读取USB摄像头图像数据，请确保USB摄像头不是接在Hub上的，USB摄像头必须直接接入设备，确保图像传输速率快。

## 参考文档

矽递科技英文Wiki文档：[How to use the SO10xArm robotic arm in Lerobot | Seeed Studio Wiki]([如何在 Lerobot 中使用 SO100/101Arm 机器人手臂 | Seeed Studio Wiki](https://wiki.seeedstudio.com/cn/lerobot_so100m/))

Huggingface Project:[Lerobot](https://github.com/huggingface/lerobot/tree/main)

Huggingface:[LeRobot](https://huggingface.co/docs/lerobot/index)

ACT or ALOHA:[Learning Fine-Grained Bimanual Manipulation with Low-Cost Hardware](https://tonyzhaozh.github.io/aloha/)

VQ-BeT:[VQ-BeT: Behavior Generation with Latent Actions](https://sjlee.cc/vq-bet/)

Diffusion Policy:[Diffusion Policy](https://diffusion-policy.cs.columbia.edu/)

TD-MPC:[TD-MPC](https://www.nicklashansen.com/td-mpc/)

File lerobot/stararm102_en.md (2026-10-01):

> Historical English integration guide. For the current installation paths, start with [LeRobot setup](README.md). Do not combine commands across plugin generations. Product descriptions below may refer to earlier hardware.

# How to use the LeRobot-starai robotic arm in Lerobot

https://github.com/user-attachments/assets/dcbd27da-9e24-4562-b682-ff3212f6ac4a

## Products Introduction

1. **Open-Source & Developer-Friendly**
   It is an open-source, developer-friendly 6+1 DoF robotic arm solution from [Fishion Star Technology Limited](https://fashionrobo.com/).
2. **Integration with LeRobot**
   Designed for integration with [LeRobot Platform](https://github.com/huggingface/lerobot) , which provides PyTorch models, datasets, and tools for imitation learning in real-world robotic tasks — including data collection, simulation, training, and deployment.
3. **Comprehensive Learning Resources**
   Provides comprehensive open-source learning resources like assembly and calibration guides, and example custom grasping tasks to assist users in quickly getting started and developing robotic applications.
4. **Compatible with Nvidia**
   Supports deployment on the reComputer Mini J4012 Orin NX 16GB platform.

## Main Features

- Ready to Go — No Assembly Required. Just Unbox and Dive into the World of AI.
- 6+1 Degrees of Freedom and a 470mm Reach — Built for Versatility and Precision.
- Parallel Gripper with 66mm Maximum Opening — Modular Fingertips for Quick-Replace Flexibility.

## Initial Environment Setup

For Ubuntu X86:

- Ubuntu 22.04
- CUDA 12+
- Python 3.10
- Troch 2.6

## Installation

### Install LeRobot

1. Environments such as pytorch and torchvision need to be installed based on your CUDA.

    Install Miniconda: For Jetson:

    ```bash
    wget https://repo.anaconda.com/miniconda/Miniconda3-latest-Linux-aarch64.sh
    chmod +x Miniconda3-latest-Linux-aarch64.sh
    ./Miniconda3-latest-Linux-aarch64.sh
    source ~/.bashrc
    ```

    Or, For X86 Ubuntu 22.04:

    ```bash
    mkdir -p ~/miniconda3
    cd miniconda3
    wget https://repo.anaconda.com/miniconda/Miniconda3-latest-Linux-x86_64.sh -O ~/miniconda3/miniconda.sh
    bash ~/miniconda3/miniconda.sh -b -u -p ~/miniconda3
    rm ~/miniconda3/miniconda.sh
    source ~/miniconda3/bin/activate
    conda init --all
    ```

2. Create and activate a fresh conda environment for lerobot

    ```bash
    conda create -y -n lerobot python=3.10 && conda activate lerobot
    ```

3. When using miniconda, install ffmpeg in your environment:

    ```bash
    conda install ffmpeg -c conda-forge
    ```

    This usually installs ffmpeg 7.X for your platform compiled with the libsvtav1 encoder. If libsvtav1 is not supported (check supported encoders with ffmpeg -encoders), you can:

    - [On any platform] Explicitly install ffmpeg 7.X using:

    ```bash
    conda install ffmpeg=7.1.1 -c conda-forge
    ```

4. Install LeRobot:

    ```bash
    cd ~/lerobot && pip install -e .
    ```

    For Jetson Jetpack devices (please ensure that Pytorch-gpu and Torchvision have been installed following Step 5 of [this tutorial](https://github.com/Seeed-Projects/reComputer-Jetson-for-Beginners/tree/main/3-Basic-Tools-and-Getting-Started/3.5-Pytorch) before proceeding with this step):

    ```bash
    conda install -y -c conda-forge "opencv>=4.10.0.84"  # Install OpenCV and other dependencies via conda, only for Jetson Jetpack 6.0+
    conda remove opencv   # Uninstall OpenCV
    pip3 install opencv-python==4.10.0.84  # Install the specified version of OpenCV using pip3
    conda install -y -c conda-forge ffmpeg
    conda uninstall numpy
    pip3 install numpy==1.26.0  # This version needs to be compatible with torchvision
    ```

5. Install Fashionstar Motor Dependencies:

     ```bash
    pip install lerobot_teleoperator_stararm102    # Install StarArm102_leader via pip
    pip install lerobot_robot_stararm102    # Install StarArm102_follower via pip
    ```

6. Check Pytorch and Torchvision

    Since installing the lerobot environment via pip will uninstall the original Pytorch and Torchvision and install the CPU versions of Pytorch and Torchvision, you need to perform a check in Python.

    ```python
    import torch
    print(torch.cuda.is_available())
    ```

    If the result is False, you need to reinstall Pytorch and Torchvision according to the [official website tutorial](https://fashionrobo.com/).

### Unboxing

https://github.com/user-attachments/assets/56130bd9-21ee-4ae4-9cac-3817ac4d659f

UC-01 debuging board switch：

### Configure arm port

Run the following command in the terminal to find USB ports associated to your arms：

```bash
lerobot-find-port
```

For example：

1. Example output when identifying the leader arm's port (e.g., `/dev/tty.usbmodem575E0031751` on Mac, or possibly `/dev/ttyUSB0` on Linux):
2. Example output when identifying the follower arm's port (e.g., `/dev/tty.usbmodem575E0032081`on Mac, or possibly `/dev/ttyUSB1` on Linux):

> [!NOTE]
>
> If the ttyUSB0 serial port cannot be identified, try the following solutions:
>
> List all USB ports.
>
> ```sh
> lsusb
> ```
>
> 
>
> Once identified, check the information of the ttyusb.
>
> ```sh
> sudo dmesg | grep ttyUSB
> ```
>
> 
>
> The last line indicates a disconnection because brltty is occupying the USB. Removing brltty will resolve the issue.
>
> ```sh
> sudo apt remove brltty
> ```
>
> 
>
> Finally，use chmod command.
>
> ```sh
> sudo chmod 777 /dev/ttyUSB*
> ```
>

## Calibrate

### For Initial Calibration

Please rotate each joint left and right to the corresponding positions.

### For Re-Calibration

Follow the on-screen prompt: enter the letter "c" and press the Enter key.

Below are the reference values. Under normal circumstances, the actual limit reference values should fall within the range of **±10°** of these references.

| Servo ID | Lower Angle Limit | Upper Angle Limit | Notes |
| --- | ---: | ---: | --- |
| motor_0  | -180°  | 180° | Rotate to the limit position |
| motor_1  | -90°  | 90° | Rotate to the limit position |
| motor_2  | -90°  | 90° | Rotate to the limit position |
| motor_3  | -180°  | 180° | No limit; rotate to reference angle |
| motor_4  | -90°  | 90° | Rotate to the limit position |
| motor_5  | -180°  | 180° | No limit; rotate to reference angle |
| motor_6  | 0°  | 100° | Rotate to the limit position |

### leader

> [!TIP]
>
> Connect the leader to /dev/ttyUSB0, or modify the command below.

```bash
lerobot-calibrate     --teleop.type=lerobot_teleoperator_stararm102 --teleop.port=/dev/ttyUSB0 --teleop.id=my_awesome_stararm102_leader_arm
```

### follower

> [!TIP]
>
> Connect the follower to /dev/ttyUSB1, or modify the command below.

```bash
lerobot-calibrate     --robot.type=lerobot_robot_stararm102 --robot.port=/dev/ttyUSB1 --robot.id=my_awesome_stararm102_follower_arm
```

## Teleoperate

https://github.com/user-attachments/assets/23b3aa00-9889-48d3-ae2c-00ad50595e0a

Then you are ready to teleoperate your robot (It won't display the cameras)! Run this simple script :

```bash
lerobot-teleoperate \
    --robot.type=lerobot_robot_stararm102 \
    --robot.port=/dev/ttyUSB1 \
    --robot.id=my_awesome_stararm102_follower_arm \
    --teleop.type=lerobot_teleoperator_stararm102 \
    --teleop.port=/dev/ttyUSB0 \
    --teleop.id=my_awesome_stararm102_leader_arm
```

After the program starts, the Hover Lock Technology remains functional.

## Add cameras

https://github.com/user-attachments/assets/82650b56-96be-4151-9260-2ed6ab8b133f

After inserting your two USB cameras, run the following script to check the port numbers of the cameras. It is important to remember that the camera must not be connected to a USB Hub; instead, it should be plugged directly into the device. The slower speed of a USB Hub may result in the inability to read image data.

```bash
lerobot-find-cameras opencv # or realsense for Intel Realsense cameras
```

The terminal will print out the following information. For example, the laptop camera is `index 2`, and the USB camera is `index 4`.

```markdown
--- Detected Cameras ---
Camera #0:
  Name: OpenCV Camera @ /dev/video2
  Type: OpenCV
  Id: /dev/video2
  Backend api: V4L2
  Default stream profile:
    Format: 0.0
    Width: 640
    Height: 480
    Fps: 30.0
--------------------
Camera #1:
  Name: OpenCV Camera @ /dev/video4
  Type: OpenCV
  Id: /dev/video4
  Backend api: V4L2
  Default stream profile:
    Format: 0.0
    Width: 640
    Height: 360
    Fps: 30.0
--------------------

Finalizing image saving...
Image capture finished. Images saved to outputs/captured_images
```

After confirming that the external camera is connected, replace the camera information below with the actual camera details. This will allow you to display the camera feed on your computer during teleoperation:

```bash
lerobot-teleoperate \
    --robot.type=lerobot_robot_stararm102 \
    --robot.port=/dev/ttyUSB1 \
    --robot.id=my_awesome_stararm102_follower_arm \
    --robot.cameras="{ front: {type: opencv, index_or_path: 2, width: 640, height: 480, fps: 30}}" \
    --teleop.type=lerobot_teleoperator_stararm102 \
    --teleop.port=/dev/ttyUSB0 \
    --teleop.id=my_awesome_stararm102_leader_arm \
    --display_data=true
```

## Record the dataset

https://github.com/user-attachments/assets/8bb25714-783a-4f29-83dd-58b457aed80c

> [!TIP]
>
> Use the features of Hugging Face Hub to upload your dataset, and please refer to the following official article link.
>
> [lmitation Learning for Robots](https://huggingface.co/docs/lerobot/il_robots?teleoperate_koch_camera=Command)
>
>

Once you're familiar with teleoperation, you can record your first dataset.

Record 10 episodes.

```bash
lerobot-record \
    --robot.type=lerobot_robot_stararm102 \
    --robot.port=/dev/ttyUSB1 \
    --robot.id=my_awesome_stararm102_follower_arm \
    --robot.cameras="{ up: {type: opencv, index_or_path: /dev/video2, width: 640, height: 480, fps: 30},front: {type: opencv, index_or_path: /dev/video4, width: 640, height: 480, fps: 30}}" \
    --teleop.type=lerobot_teleoperator_stararm102 \
    --teleop.port=/dev/ttyUSB0 \
    --teleop.id=my_awesome_stararm102_leader_arm \
    --display_data=true \
    --dataset.repo_id=starai/record-test \
    --dataset.episode_time_s=30 \
    --dataset.reset_time_s=30 \
    --dataset.num_episodes=10 \
    --dataset.push_to_hub=False \
    --dataset.single_task="Grab the black cube"
```

## Replay an episode

```bash
lerobot-replay \
    --robot.type=lerobot_robot_stararm102 \
    --robot.port=/dev/ttyUSB1 \
    --robot.id=my_awesome_stararm102_follower_arm \
    --dataset.repo_id=starai/record-test \
    --dataset.episode=1 # choose the episode you want to replay
```

## Train

Train a policy to control your robot

```bash
lerobot-train \
  --dataset.repo_id=starai/record-test \
  --policy.type=act \
  --output_dir=outputs/train/act_stararm102_test \
  --job_name=act_stararm102_test \
  --policy.device=cuda \
  --wandb.enable=False \
  --policy.repo_id=starai/my_policy
```

To resume training from a checkpoint

```bash
lerobot-train \
  --config_path=outputs/train/act_viola_test/checkpoints/last/pretrained_model/train_config.json \
  --resume=true
```

## Evaluate your policy

Run the following command to record 10 evaluation episodes:

```bash
lerobot-record  \
  --robot.type=lerobot_robot_stararm102 \
  --robot.port=/dev/ttyUSB1 \
  --robot.cameras="{ up: {type: opencv, index_or_path: /dev/video2, width: 640, height: 480, fps: 30},front: {type: opencv, index_or_path: /dev/video4, width: 640, height: 480, fps: 30}}" \
  --robot.id=my_awesome_stararm102_follower_arm \
  --display_data=false \
  --dataset.repo_id=starai/eval_record-test \
  --dataset.single_task="Put lego brick into the transparent box" \
  --policy.path=outputs/train/act_stararm102_test/checkpoints/last/pretrained_model
  # <- Teleop optional if you want to teleoperate in between episodes \
  # --teleop.type=lerobot_teleoperator_stararm102 \
  # --teleop.port=/dev/ttyUSB0 \
  # --teleop.id=my_awesome_stararm102_leader_arm \
```

## Reference Documentation

Seeed Wiki: [SO-100/101 LeRobot tutorial](https://wiki.seeedstudio.com/lerobot_so100m/)

Huggingface Project:[Lerobot](https://github.com/huggingface/lerobot/tree/main)

Huggingface:[LeRobot](https://huggingface.co/docs/lerobot/index)

ACT or ALOHA:[Learning Fine-Grained Bimanual Manipulation with Low-Cost Hardware](https://tonyzhaozh.github.io/aloha/)

VQ-BeT:[VQ-BeT: Behavior Generation with Latent Actions](https://sjlee.cc/vq-bet/)

Diffusion Policy:[Diffusion Policy](https://diffusion-policy.cs.columbia.edu/)

TD-MPC:[TD-MPC](https://www.nicklashansen.com/td-mpc/)

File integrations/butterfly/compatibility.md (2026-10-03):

# Butterfly integration compatibility

[Integration overview](README.md) · [Setup](setup.md)

The following describes the [reviewed upstream revision](https://github.com/butterfly-community/robot-arm/tree/08498c31c56cf339601851851225bf111f89c82d). It records upstream documentation, not a Fashion Star hardware test result.

| Component | Upstream configuration / requirement | What to confirm |
| --- | --- | --- |
| Robot | StarArm-102 with six arm joints and a gripper | Exact product variant, hardware revision, joint limits, and zero convention |
| Servos | RA8-U35H-M for the six axes and gripper | Actual installed models and supported firmware; do not infer these from bus IDs |
| Camera | RealSense D415 RGB-D camera | Device access, color/depth alignment, and calibration; other cameras need validation |
| Runtime | Docker-managed frontend, Rust/Dora services, perception compute, and ROS/MoveIt motion services | Host support, device passthrough, model files, build prerequisites, and compute requirements in upstream deployment instructions |
| Natural-language interface | Compatible AI model service with the required image and tool-call capabilities | Provider, credentials, endpoint compatibility, and any service charges |
| Software-only mode | Simulated camera data and virtual joint feedback | Software workflow validation only; not physical grasp reliability |

The reviewed deployment document lists separate base images, including Ubuntu 26.04, Python 3.11 for perception, and Node.js 24 for the frontend. These are components of the upstream container stack, not a claim that this repository's ACT or ROS 2 Humble environments can run the application unchanged. No minimum GPU/VRAM specification is asserted here.

## Model and driver boundary

The partner fixes its vendor model source to commit `0896306e40891c3ee4c97228e85dd708d61326de`, applies model/dynamics/ROS-interface patches, and uses its own Rust execution service. Do not replace these assets with this repository's current URDF or run both serial-control stacks against the same arm.

Review the partner's [StarArm-102 model and driver conventions](https://github.com/butterfly-community/robot-arm/blob/08498c31c56cf339601851851225bf111f89c82d/docs/STARARM-102.md) and [deployment requirements](https://github.com/butterfly-community/robot-arm/blob/08498c31c56cf339601851851225bf111f89c82d/docs/DOCKER.md). Joint mappings, camera extrinsics, and ACT calibration files are not assumed interchangeable.

## Validation still needed

- Match the partner's physical setup to a specific 102 product and revision.
- Record the host, compute hardware, software versions, and model-service configuration used for a successful setup.
- Reproduce the software-only workflow, then communication, calibration, and a physical pick-and-place task.
- Record observed limitations and results before marking an entry as Fashion Star validated.

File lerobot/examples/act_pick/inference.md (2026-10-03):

# Run the released ACT model

[Model overview and scene photos](README.md) · [Troubleshooting](../../../docs/troubleshooting.md)

Follow these steps in order. Downloading the model does not move the arm; calibration and `lerobot-record` connect to the hardware and can change torque or command motion.

## Install the environment

The existing release guide records Ubuntu 22.04, Python 3.10, LeRobot 0.4.1, and the StarArm robot/teleoperator plugins at 0.0.1. With [Miniforge](https://github.com/conda-forge/miniforge#install) installed:

```bash
conda create -n stararm102-act python=3.10 -y
conda activate stararm102-act
conda install -c conda-forge ffmpeg -y
python -m pip install "lerobot==0.4.1" \
  "lerobot-robot-stararm102==0.0.1" \
  "lerobot-teleoperator-stararm102==0.0.1"
```

The downloaded policy and preprocessor are configured for `cuda`. The documented first-run path therefore requires an NVIDIA GPU and compatible driver. The original guide reports an RTX 5070 Ti and this CUDA wheel combination:

```bash
python -m pip install torch==2.7.1 torchvision==0.22.1 torchaudio==2.7.1 \
  --index-url https://download.pytorch.org/whl/cu128
```

For another GPU, choose a supported build using the [PyTorch installation guide](https://pytorch.org/get-started/locally/) while retaining LeRobot 0.4.1's dependency bounds. The release does not provide a complete dependency lock or a CPU performance benchmark. Do not install the refactored HD/FL package into this environment.

```bash
python -m pip check
python -c "import torch; print(torch.__version__, torch.cuda.is_available()); print(torch.cuda.get_device_name(0) if torch.cuda.is_available() else 'CPU')"
lerobot-record --help
python -m pip freeze > stararm102-act-environment.txt
```

**Success:** dependency check passes, `lerobot-record --help` works, and the expected compute device is available. If CUDA is unavailable when expected, resolve the driver/wheel mismatch before attempting the task.

## Download and verify

Run in a new download directory. From the repository root, copy its checksum file first:

```bash
mkdir -p "$HOME/Downloads/stararm102-act"
cp lerobot/examples/act_pick/SHA256SUMS.txt "$HOME/Downloads/stararm102-act/"
cd "$HOME/Downloads/stararm102-act"
curl -fL -o stararm102_pick_act_torch271.tar.gz \
  https://github.com/servodevelop/Star-Arm-102/releases/download/act-pick-v1.0.0/stararm102_pick_act_torch271.tar.gz
sha256sum -c SHA256SUMS.txt
mkdir -p "$HOME/models/stararm102_pick_act_torch271"
tar -xzf stararm102_pick_act_torch271.tar.gz -C "$HOME/models/stararm102_pick_act_torch271"
ls "$HOME/models/stararm102_pick_act_torch271/pretrained_model"
```

Only extract after the checksum reports `OK`. Use an empty model directory to avoid mixing files from older downloads. The policy path used below is the `pretrained_model` directory, not its parent or just a weight file.

## Prepare the follower and cameras

Complete [hardware setup](../../../docs/hardware-setup.md) and the [communication check](../../../python-sdk/README.md#check-communication-without-commanding-motion). Close other processes using the arm's serial port. Replace `/dev/ttyUSB1` with the FL port.

```bash
lerobot-calibrate \
  --robot.type=lerobot_robot_stararm102 \
  --robot.port=/dev/ttyUSB1 \
  --robot.id=customer_stararm102_follower
```

Follow the range-recording prompts, including the gripper. Support the arm when joints unlock. Keep the calibration ID unchanged during inference. Do not substitute another arm's calibration file.

Identify both cameras:

```bash
lerobot-find-cameras opencv
```

Check the saved camera images reported by the command. Assign the overhead camera to **`up`** and the frontal camera to **`front`**. The command below uses `/dev/video0` and `/dev/video1` as examples; use the actual capture devices. Some cameras expose additional non-capture devices. Check the view, 640 × 480 resolution, 30 FPS, and scene against the [setup photos](README.md#match-the-scene).

These camera names are model input keys. Do not rename them to `first_person` or `third_person`, or swap their views.

## Run one short trial

Secure the arm and cameras. Match the shown starting scene, remove unrelated objects, and keep people clear of the reachable area. Be ready to switch off servo power. The command below runs an autonomous policy and can move the arm immediately.

```bash
lerobot-record \
  --robot.type=lerobot_robot_stararm102 \
  --robot.port=/dev/ttyUSB1 \
  --robot.id=customer_stararm102_follower \
  --robot.cameras='{up: {type: opencv, index_or_path: /dev/video0, width: 640, height: 480, fps: 30}, front: {type: opencv, index_or_path: /dev/video1, width: 640, height: 480, fps: 30}}' \
  --policy.path="$HOME/models/stararm102_pick_act_torch271/pretrained_model" \
  --display_data=true \
  --dataset.repo_id=customer/eval_stararm102_pick_run1 \
  --dataset.root="$HOME/lerobot_data/eval_stararm102_pick_run1" \
  --dataset.num_episodes=1 \
  --dataset.episode_time_s=30 \
  --dataset.reset_time_s=10 \
  --dataset.single_task="Place the block in the center" \
  --dataset.push_to_hub=false
```

The task string describes the recording; it does not teach this ACT model a different task. `customer/...` is a local dataset identifier here, and uploading is disabled. Choose a new run name and directory for another trial instead of deleting existing recordings.

**Success:** the checkpoint loads without feature mismatches, both views display correctly, the arm performs the intended task, and one local episode is saved. If motion is unexpected, stop and investigate the setup; a running process alone is not a successful trial. `Ctrl+C` requests process exit and is not a hardware emergency stop.

## Optional leader for later trials

First calibrate a compatible leader in this same release environment using the [LeRobot guide](../../README.md#calibrate-the-ld-leader-and-fl-follower). After a successful first trial, add these options to the recording command when you need leader control during reset intervals:

```text
--teleop.type=lerobot_teleoperator_stararm102
--teleop.port=/dev/ttyUSB0
--teleop.id=customer_stararm102_leader
```

Do not reach into the workspace during policy execution. Increase the episode count only after checking the first trial. The old leader plugin does not provide the refactored HD button feature.

## If the trial fails

| Symptom | Check first |
| --- | --- |
| Unknown robot type / import error | Active environment, installed 0.0.1 packages, and `pip check` |
| `Motor_0` vs `shoulder_pan` feature mismatch | Wrong plugin generation; recreate the release environment |
| Missing image feature | Exact camera names `up` and `front` |
| Missing or black camera image | Device mapping, capture support, permissions, and another process using the camera |
| Model loads but misses the block | Calibration, camera views, starting pose, object, lighting, and scene match |
| Torch/CUDA/video decoder error | Preserve the full traceback and environment file; verify wheel/driver and FFmpeg compatibility |

See [support information to include](../../../docs/troubleshooting.md#report-a-problem). Never compensate for a feature mismatch by blindly renaming policy action keys.

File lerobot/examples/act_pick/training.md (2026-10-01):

# Train your own ACT task

[Try the supplied policy first](inference.md) · [Choose a LeRobot integration](../../README.md)

Phase one provides an English path to the released model and a starting point for collecting your own task. A complete step-by-step training course belongs to the later Wiki phase.

## What is available now

- The released 100,000-step ACT checkpoint and [scene photographs](README.md).
- [Calibration and teleoperation](../../README.md) for the release-compatible plugins.
- A [recording and starter training example](../../lerobot-stararm102/README.md#record-your-own-demonstrations) for the refactored HD/FL integration. Its dataset has different joint features and is not interchangeable with the released model.

The archive includes `train_config.json`: 100,000 steps, batch size 8, seed 1000, four data workers, ACT chunk size 100, and AdamW learning rate `1e-5`. It also contains the policy configuration and normalization processors. The dataset path in that file points to the original training machine; it is not a downloadable dataset URL.
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

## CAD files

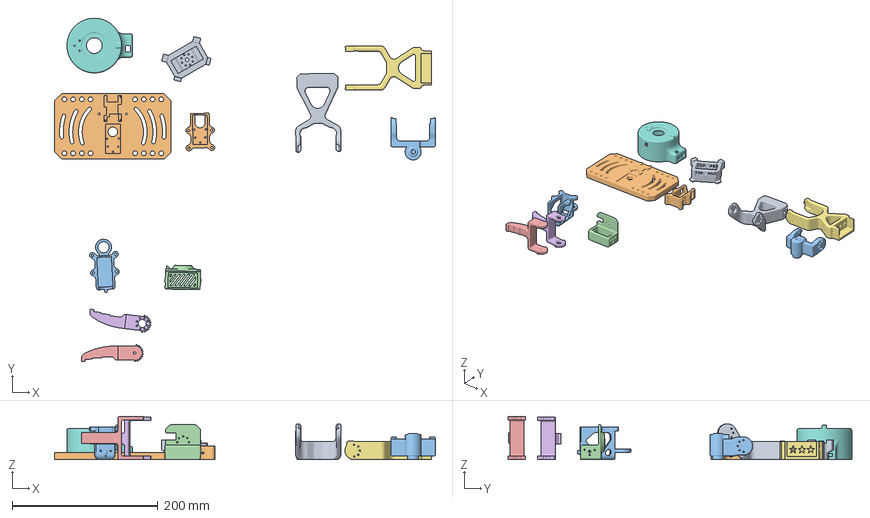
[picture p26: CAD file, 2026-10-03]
hardware/102-fl/printing/3mf/star-arm-102-fl-complete-print-project.3mf
522.5 x 471.0 x 59.6 mm
star102_link3.STEP
star102_link5.STEP
star102_link6夹爪.STEP
star102_夹爪主体.STEP
star102_指尖右.STEP
star102_指尖左.STEP
star102_link2.STEP
star102底座上.STEP
star102_link1.STEP
star102底座下.STEP
star102_link4.STEP

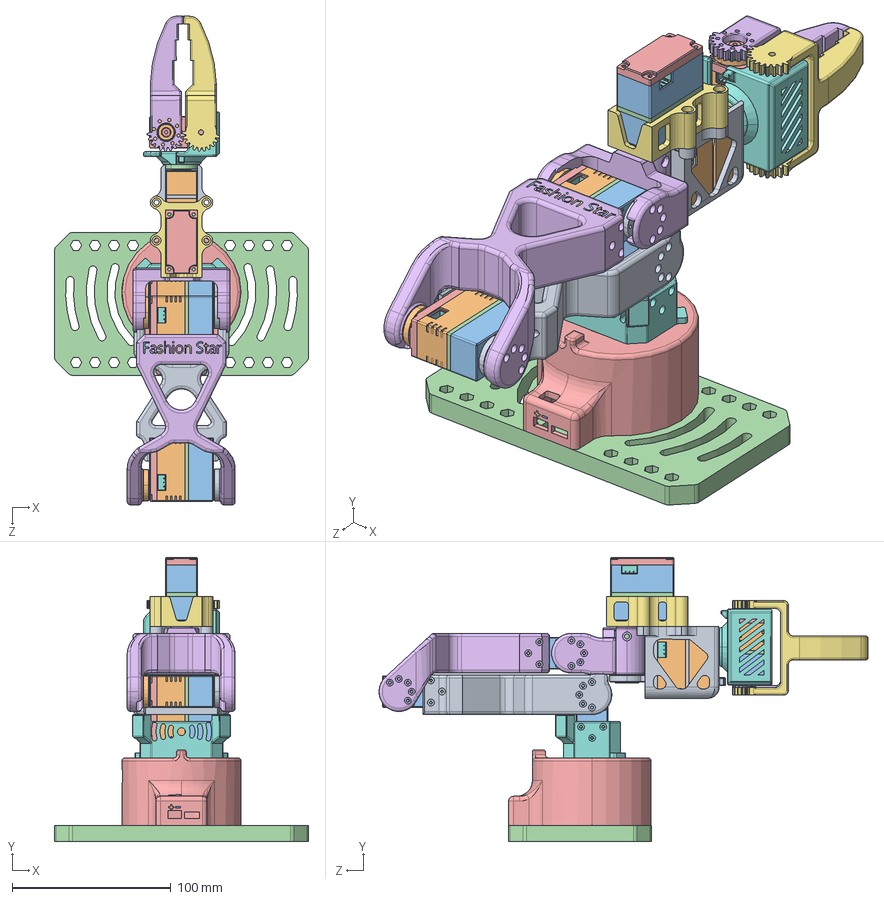
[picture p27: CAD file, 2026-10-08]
hardware/102-fl/step/assembly/star-arm-102-fl-assembly-export-2026-10-08.step
160.0 x 178.9 x 307.9 mm
______ 25-50kg________-______^star-arm-102-fl-export-2026-09-27(2)_star-arm-102-fl-export-2026-09-27.STEP x 4
______ RX8-U29H-M 3D.STEP^star-arm-102-fl-export-2026-09-27(2)_star-arm-102-fl-export-2026-09-27.STEP
#3______1^star-arm-102-fl-export-2026-09-27(2)_star-arm-102-fl-export-2026-09-27.STEP
#4__________^star-arm-102-fl-export-2026-09-27(2)_star-arm-102-fl-export-2026-09-27.STEP
__link1________^star-arm-102-fl-export-2026-09-27(2)_star-arm-102-fl-export-2026-09-27.STEP
link2_rebot^star-arm-102-fl-export-2026-09-27(2)_star-arm-102-fl-export-2026-09-27.STEP
________-0^star-arm-102-fl-export-2026-09-27(2)_star-arm-102-fl-export-2026-09-27.STEP
star102_______^star-arm-102-fl-export-2026-09-27(2)_star-arm-102-fl-export-2026-09-27.STEP
star102_______^star-arm-102-fl-export-2026-09-27(2)_star-arm-102-fl-export-2026-09-27-0.STEP
star102_________^star-arm-102-fl-export-2026-09-27(2)_star-arm-102-fl-export-2026-09-27.STEP
star102_link6____^star-arm-102-fl-export-2026-09-27(2)_star-arm-102-fl-export-2026-09-27.STEP
^_RP8-U45H-M-C028(2)_RP8-U45H-M-C028.STEP
____ (2) ^_RP8-U45H-M-C028(2)_RP8-U45H-M-C028.STEP
____ (3) ^_RP8-U45H-M-C028(2)_RP8-U45H-M-C028.STEP
______^_RP8-U45H-M-C028(2)_RP8-U45H-M-C028.STEP
3pin____^_RP8-U45H-M-C028(2)_RP8-U45H-M-C028.STEP x 2
________(2)^RP8-U45H-M-C028(2)_RP8-U45H-M-C028.STEP
main-horn-25T-8holes-3D.step^RP8-U45H-M-C028(2)_RP8-U45H-M-C028.STEP
link3_rebot_V2(3mm).step.STEP

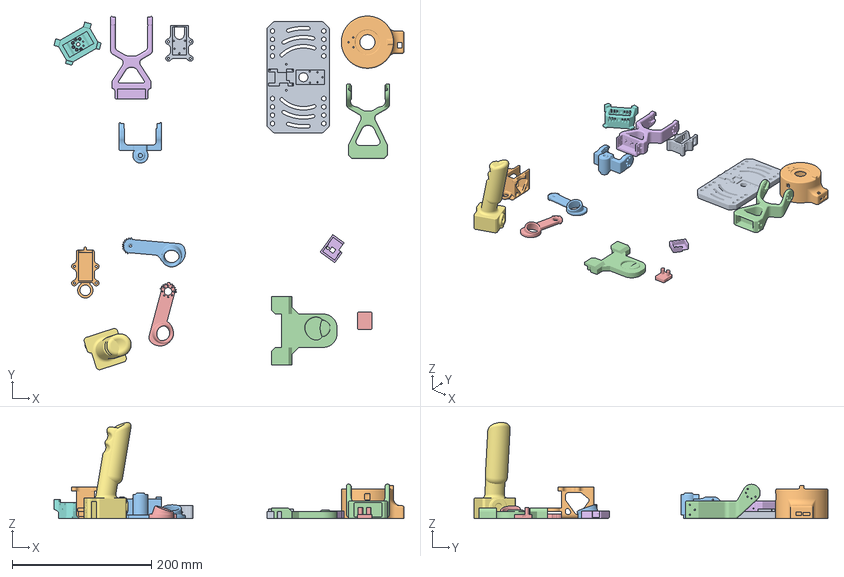
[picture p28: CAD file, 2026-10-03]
hardware/102-hd/printing/3mf/star-arm-102-hd-complete-print-project.3mf
502.6 x 508.2 x 137.9 mm
star102_link5.STEP
star102_link6手柄.STEP
star102_指环右.STEP
star102_link3.STEP
star102_指环左.STEP
star102_link2.STEP
star102_手柄.STEP
star102_link1.STEP
star102底座下.STEP
star102底座上.STEP
star102_link4.STEP
star 102_底托.STEP
按钮底座.STEP
按钮盖子.STEP

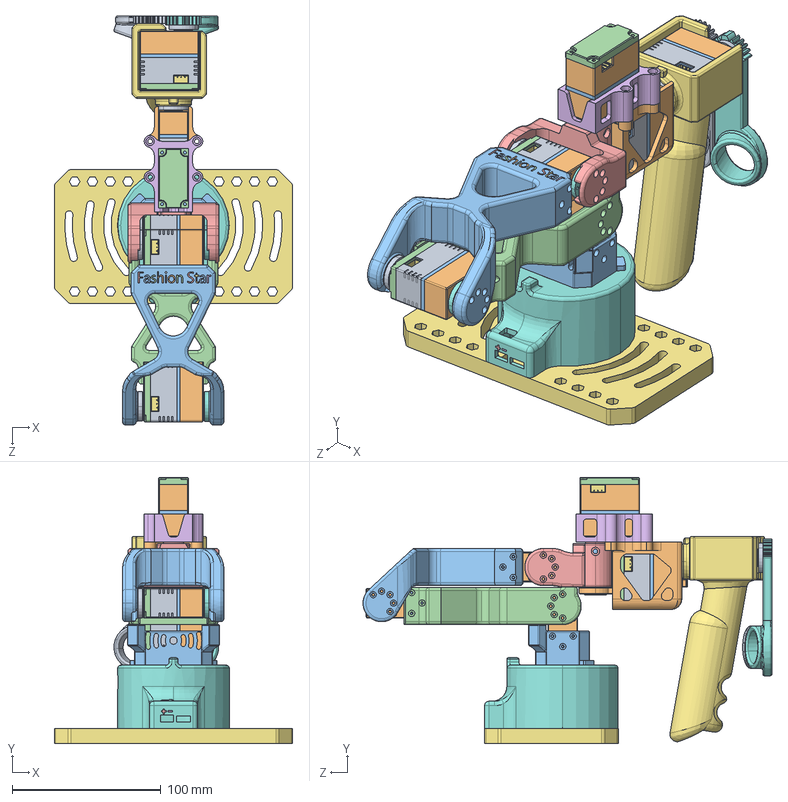
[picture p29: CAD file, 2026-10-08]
hardware/102-hd/step/assembly/star-arm-102-ld-hd-assembly-export-2026-10-08.step
160.0 x 178.9 x 274.8 mm
______ 25-50kg________-______^star-arm-102-ld-hd-assembly-export-2026-07-21 (1)_star-arm-102-ld-hd-assembly-export-2026-10-8 .STEP x 3
______ RX8-U29H-M 3D.STEP^star-arm-102-ld-hd-assembly-export-2026-07-21 (1)_star-arm-102-ld-hd-assembly-export-2026-10-8 .STEP
#3______1^star-arm-102-ld-hd-assembly-export-2026-07-21 (1)_star-arm-102-ld-hd-assembly-export-2026-10-8 .STEP
#4__________^star-arm-102-ld-hd-assembly-export-2026-07-21 (1)_star-arm-102-ld-hd-assembly-export-2026-10-8 .STEP
____^star-arm-102-ld-hd-assembly-export-2026-07-21 (1)_star-arm-102-ld-hd-assembly-export-2026-10-8 .STEP
________^star-arm-102-ld-hd-assembly-export-2026-07-21 (1)_star-arm-102-ld-hd-assembly-export-2026-10-8 .STEP
________2^star-arm-102-ld-hd-assembly-export-2026-07-21 (1)_star-arm-102-ld-hd-assembly-export-2026-10-8 .STEP
#5__________ ^star-arm-102-ld-hd-assembly-export-2026-07-21 (1)_star-arm-102-ld-hd-assembly-export-2026-10-8 .STEP
__link1________^star-arm-102-ld-hd-assembly-export-2026-07-21 (1)_star-arm-102-ld-hd-assembly-export-2026-10-8 .STEP
link2_rebot^star-arm-102-ld-hd-assembly-export-2026-07-21 (1)_star-arm-102-ld-hd-assembly-export-2026-10-8 .STEP
________-0^star-arm-102-ld-hd-assembly-export-2026-07-21 (1)_star-arm-102-ld-hd-assembly-export-2026-10-8 .STEP
^_RP8-U45H-M-C028(2)_RP8-U45H-M-C028.STEP x 2
____ (2) ^_RP8-U45H-M-C028(2)_RP8-U45H-M-C028.STEP x 2
____ (3) ^_RP8-U45H-M-C028(2)_RP8-U45H-M-C028.STEP x 2
______^_RP8-U45H-M-C028(2)_RP8-U45H-M-C028.STEP x 2
3pin____^_RP8-U45H-M-C028(2)_RP8-U45H-M-C028.STEP x 4
________(2)^RP8-U45H-M-C028(2)_RP8-U45H-M-C028.STEP x 2
main-horn-25T-8holes-3D.step^RP8-U45H-M-C028(2)_RP8-U45H-M-C028.STEP x 2
link3_rebot_V2(3mm).step.STEP

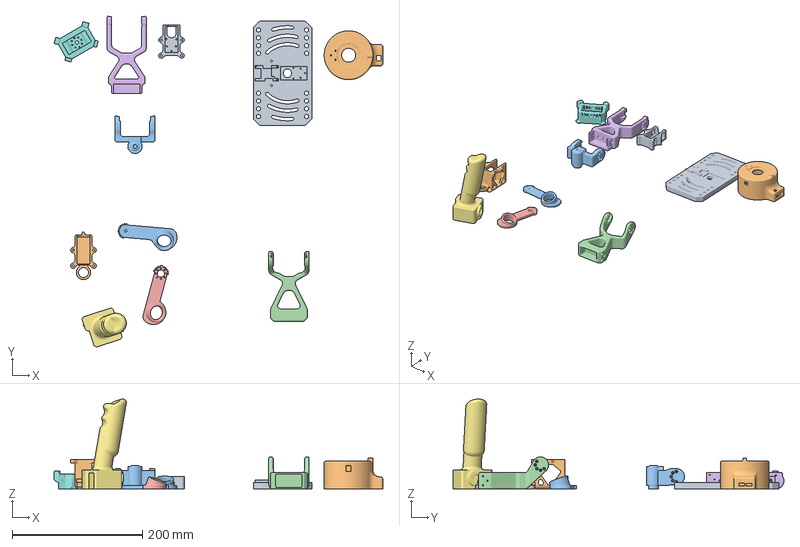
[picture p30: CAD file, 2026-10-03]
hardware/102-ld/printing/3mf/star-arm-102-ld-complete-print-project.3mf
504.6 x 508.2 x 137.9 mm
star102_link5.STEP
star102_link6手柄.STEP
star102_指环右.STEP
star102_link3.STEP
star102_指环左.STEP
star102_link2.STEP
star102_手柄.STEP
star102_link1.STEP
star102底座下.STEP
star102底座上.STEP
star102_link4.STEP

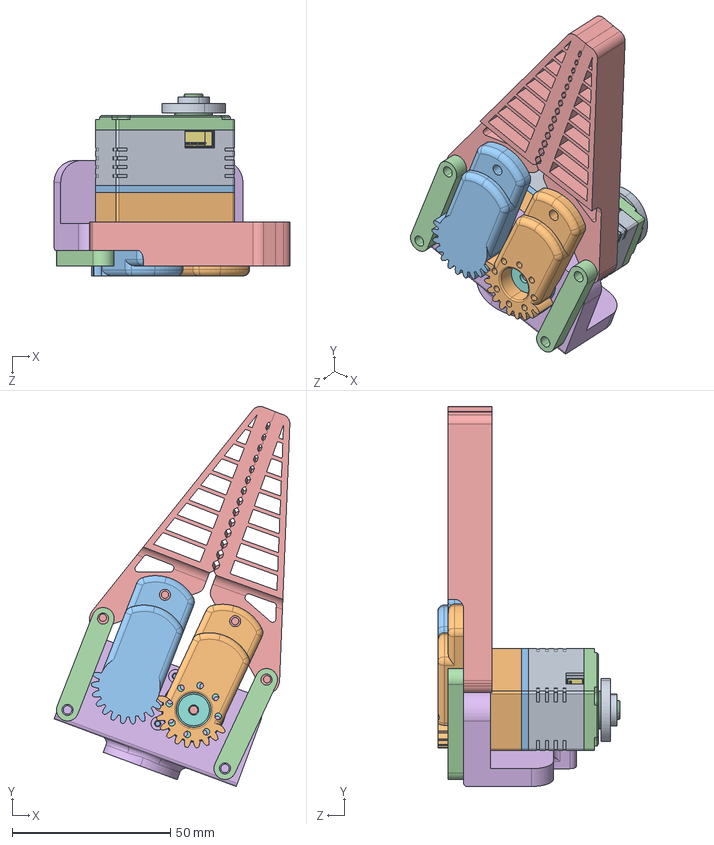
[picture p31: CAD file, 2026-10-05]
hardware/flexible-gripper/step/assembly/dual-shaft-servo-flexible-gripper-assembly.step
74.6 x 120.2 x 57.7 mm
华馨京 25-50kg双轴舵机-带舵盘
ﾈ瞎ﾔｼﾐﾗｦ1
ﾈ瞎ﾔｼﾐﾗｦ2
蟀裝 x 2
柔性夹爪指尖
柔性夹爪指尖2
双轴柔性夹爪主体

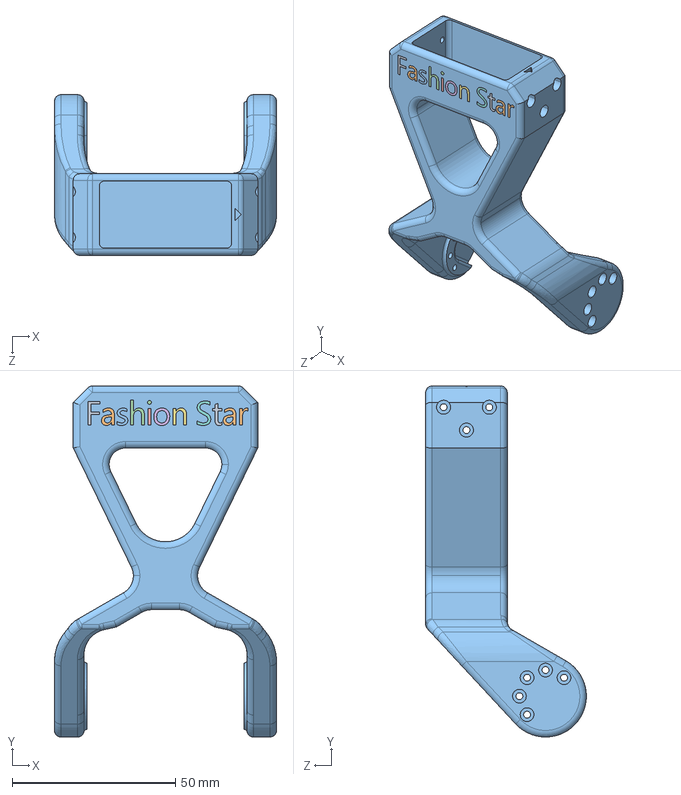
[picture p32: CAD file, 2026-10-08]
hardware/102-fl/step/parts/star-arm-102-link3.step
68.0 x 107.5 x 49.2 mm

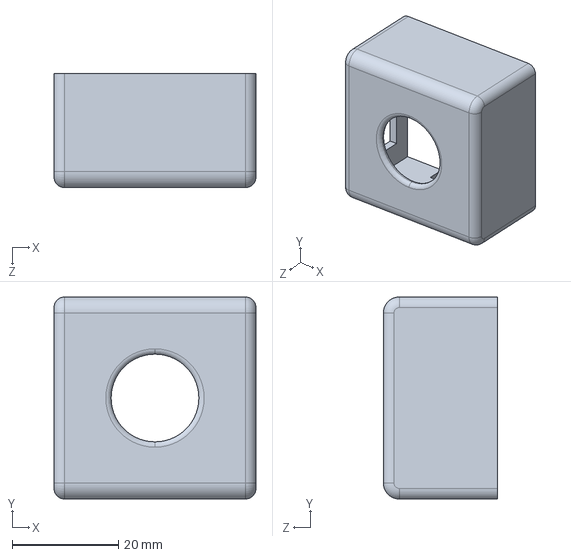
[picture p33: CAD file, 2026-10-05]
hardware/camera-module/step/parts/first-person-camera-cover-snap-fit.step
38.0 x 38.0 x 21.5 mm

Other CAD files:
hardware/star-arm-102-hd/step/assembly/star-arm-102-ld-hd-assembly-export-2026-07-21.step
hardware/star-arm-102-ld/step/assembly/star-arm-102-ld-hd-assembly-export-2026-07-21.step
hardware/102-fl/drawings/star-arm-102-fl-drawing-2026-07-13.dwg
hardware/102-ld/drawings/star-arm-102-ld-drawing-2026-07-13.dwg
hardware/102-fl/printing/3mf/star-arm-102-base-bottom.3mf
hardware/102-fl/printing/3mf/star-arm-102-base-top.3mf
hardware/102-fl/printing/3mf/star-arm-102-fingertip-left.3mf
hardware/102-fl/printing/3mf/star-arm-102-fingertip-right.3mf
hardware/102-fl/printing/3mf/star-arm-102-gripper-body.3mf
hardware/102-fl/printing/3mf/star-arm-102-link1.3mf
hardware/102-fl/printing/3mf/star-arm-102-link2.3mf
hardware/102-fl/printing/3mf/star-arm-102-link4.3mf
hardware/102-fl/printing/3mf/star-arm-102-link5.3mf
hardware/102-fl/printing/3mf/star-arm-102-link6-gripper.3mf
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

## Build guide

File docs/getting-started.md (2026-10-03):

# Get started with Star Arm 102

[Home](../README.md) · [Troubleshooting](troubleshooting.md)

## 1. Identify your equipment

Check the product/order label before selecting software. The arms look similar; use the model label rather than appearance alone.

| Model | Role | First task |
| --- | --- | --- |
| 102-LD | Lightweight, hand-guided leader | Read its seven servo IDs, then teleoperate a compatible follower |
| 102-HD | Pose-holding leader | Confirm the supplied button board/firmware, then use the HD instructions |
| 102-FL | Follower for task execution | Check communication and calibration before sending motion commands |

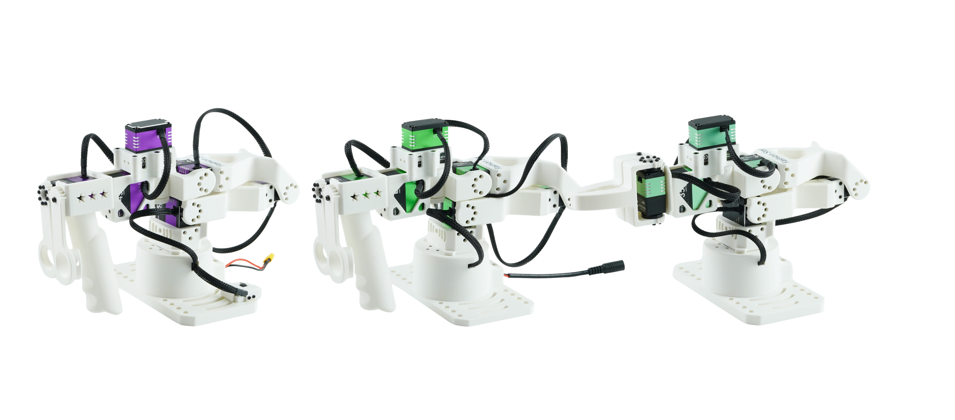
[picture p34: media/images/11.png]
Star Arm 102 overview


For ordering and product identification, see the [official series page](https://fashionstar.com.hk/robot-arm/star-arm-102/). A parts kit first needs assembly; [available DIY resources](../hardware/README.md) are organized by LD, HD, and FL with per-model availability status.

For a third-party follower, use the [cross-brand pairing directory](../integrations/README.md) and its hardware-specific preparation. The FL steps below are for Star Arm followers.

## 2. Prepare and connect

Follow [hardware setup](hardware-setup.md). You need the correct power adapter for each arm, a fixed base, USB data cables, and a computer. The customer examples target Ubuntu 22.04. Cameras are needed for the ACT demo, but not for a first communication or direct teleoperation check.

**Success:** each connected arm has an identifiable serial port, and its model and power adapter match. USB port numbers in examples are placeholders.

## 3. Select one path

| Your setup / goal | Follow this guide |
| --- | --- |
| LD + FL: first movement | [Python direct teleoperation](../python-sdk/README.md) |
| HD + FL: first movement | [Python direct teleoperation](../python-sdk/README.md), including HD button configuration |
| FL only: confirm the connection | [Communication check](../python-sdk/README.md#check-communication-without-commanding-motion) |
| FL + two cameras: run the provided model | [Pretrained ACT model](../lerobot/examples/act_pick/inference.md) |
| LD + FL: record demonstrations | [LeRobot release-compatible setup](../lerobot/README.md#release-compatible-environment) |
| HD + FL: LeRobot with button integration | [Refactored HD/FL setup](../lerobot/lerobot-stararm102/README.md) |
| Leader + Galaxea A1 / Lumos Touch / YAM | [Choose your follower pairing](../integrations/README.md) |
| Leader + reBot B601 | [reBot guide](../integrations/seeed-rebot/README.md) |
| ROS 2 development | [ROS 2 Humble](../ros2-humble/README.md) |

Do not install all paths into one environment. The [compatibility table](compatibility.md) explains which combinations have release evidence and which still require hardware validation.

## 4. Check before motion

Use the Python communication check to identify servos before direct teleoperation. LeRobot users must also run their selected plugin's calibration procedure and keep the same device ID in subsequent commands. Each guide describes its own zero/reference convention; do not copy calibration files across plugin generations.

**Success:** all seven servo IDs respond; calibration, when required, is saved; a small leader movement produces the expected follower movement. Start without cameras so that communication and motion can be checked independently.

## 5. Continue to the ACT demo

After basic checks, set up the two cameras and reproduce the [ACT workspace](../lerobot/examples/act_pick/inference.md#prepare-the-follower-and-cameras). Start with one trial. You do not need to train this supplied policy yourself.

If a step fails, stop there and use [troubleshooting](troubleshooting.md). Include the model, environment, command, and full error when [reporting an issue](https://github.com/servodevelop/Star-Arm-102/issues/new/choose).

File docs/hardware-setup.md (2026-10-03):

# Hardware setup

[Get started](getting-started.md) · [Hardware files](../hardware/README.md)

## Power and contents

Check the supplied adapter, arm label, and order packing list. Existing repository specifications list:

| Model | Listed power specification | Connector listed for the arm |
| --- | --- | --- |
| 102-LD | 12 V, 3 A | DC5521 |
| 102-HD | 12 V, 10 A | XT30 |
| 102-FL | 12 V, 10 A | XT30 |

These values are carried forward from the product specifications, not newly measured. Earlier accessory lists describe spare adapter cables separately; do not select a supply by the spare cable alone. If your supplied hardware differs, confirm the revision with Fashion Star before connecting power. Do not use a reBot follower's supply for a 102 leader.

Prepare a stable desk, base clamps, USB data cables, and the correct independent power supply for each arm. Check your order for cameras and mounts: a bare arm is not a complete two-camera ACT setup.

## Connect the arms

1. Switch off power before connecting or changing servo/power cables.
2. Fix the bases and clear the reachable area. Support the arms when torque is off; joints can move under gravity.
3. Connect each arm's servo bus to its own UC-01 hub as supplied. Use the supplied wiring; do not infer pin polarity from a photo.
4. Connect each hub to the computer with a USB data cable.
5. Connect the matching supply to each arm and power on.

```text
                    Ubuntu computer
                    /             \
                 USB               USB
                  |                 |
             Leader UC-01      Follower UC-01
                  |                 |
               LD / HD             FL
                  |                 |
           Matching supply    Matching supply
```

USB provides the data connection; it does not replace the servo power supply. A single FL uses only the right-hand branch. The ACT demo additionally connects two cameras to the computer.

## Identify serial ports

Connect one arm at a time and run:

```bash
python3 -m serial.tools.list_ports -v
```

This command requires `pyserial`, installed by the [Python setup](../python-sdk/README.md). On Ubuntu you can also inspect:

```bash
ls -l /dev/serial/by-id/
ls -l /dev/ttyUSB* /dev/ttyACM*
```

Some adapters do not expose a unique by-ID path. Label the cables and record which port belongs to each arm. Numbering can change after reconnection. The examples use `/dev/ttyUSB0` for the leader and `/dev/ttyUSB1` for FL; replace them with your actual ports.

For Ubuntu serial permissions:

```bash
sudo usermod -aG dialout "$USER"
```

Log out and back in, then check `id -nG`. For a temporary session, grant access only to the identified device, for example `sudo chmod a+rw /dev/ttyUSB0`. Do not change permissions on every USB device.

**Success:** both ports are visible and accessible. Continue with the [communication check](../python-sdk/README.md#check-communication-without-commanding-motion).

## Reference pose and stopping

Before direct Python teleoperation, place both arms in their matching physical zero/reference poses. The script resets multi-turn counts on connection; it does not run LeRobot calibration. If the reference pose for your hardware revision is unclear, confirm it before commanding motion. For LeRobot, follow the selected plugin's calibration prompts instead.

`Ctrl+C` requests program termination; it is not a hardware emergency stop and does not guarantee torque removal or immediate motion cancellation. Know how to switch off servo power while keeping clear of moving parts. Never rely on unplugging USB to stop the arm. On unexpected movement or feedback errors, stop the session and check the setup before restarting.

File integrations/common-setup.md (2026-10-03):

# Prepare a Cross-Brand Pairing

[Pairing directory](README.md) · [Capability status](compatibility.md)

## 1. Identify both arms

Record the Star Arm 102-LD or HD revision and the exact follower model. For HD, also identify the button board and firmware. Read the leader's [hardware information](../hardware/README.md) and [wiring guide](../docs/hardware-setup.md); use the follower manufacturer's instructions for its power and connection requirements.

## 2. Choose a documented implementation

Open your model's pairing guide and select either its direct Python adapter or its LeRobot integration. If commands or versions are pending, obtain the matching integration package and setup record from your supplier before running a different model's example. Use a separate environment for each integration.

## 3. Confirm the mapping

The guide must specify joint mapping or end-effector pose mapping, units, direction, offsets, motion limits, gripper conversion, and the zero/reference procedure. Confirm whether HD buttons hold the leader, pause the follower, or perform another documented action. Do not assume equal joint counts imply compatible motion.

## 4. Validate the first movement

Check communication using each device's documented driver. Secure both arms and follow the pairing's calibration and stopping procedure. Verify small movements and the gripper before adding cameras or data recording. Do not use the FL-specific Python driver or its bus scan on an unrelated follower.

## 5. Record and extend

Save the environment versions and test results described in the [evidence matrix](compatibility.md). Add data collection only after teleoperation works; validate training and inference independently with the follower's action representation.

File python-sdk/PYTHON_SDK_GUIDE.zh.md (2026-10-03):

> 中文补充资料：保留原有使用说明。当前版本与英文入口中的兼容性说明为准。

# Python SDK - StarArm 102 机械臂控制





---

## 📖 简介

Python SDK 是 StarArm 102 机械臂的 Python 控制接口，提供简单易用的 Python API 用于机械臂的实时控制。该 SDK 支持主从遥操作模式，可通过 UART 串口直接控制机械臂舵机。

### ✨ 核心特性

- 🤖 **主从遥操作**：支持 Leader 机械臂实时控制 Follower 机械臂
- ⚡ **高实时性**：支持 100Hz+ 的控制频率
- 🎯 **多关节控制**：同时控制 7 个舵机关节
- 🔒 **HD 锁定状态扩展**：Star Arm 102-HD 可通过锁定功能按键板提供锁定 / 解锁状态
- 📊 **性能监控**：实时显示控制频率
- 🔧 **简单易用**：基于 Python，无需复杂配置

---

## 🚀 快速开始

### 环境要求

| 项目 | 要求 |
|---|---|
| 操作系统 | Ubuntu 22.04 |
| Python 版本 | Python 3.8+ |
| 硬件设备 | StarArm 102 机械臂 (Leader + Follower) |
| 串口设备 | 2个 USB 转串口设备 |

### 安装依赖

```bash
# 安装 Python 依赖包
pip install pyserial fashionstar-uart-sdk
```

### 硬件连接

1. **连接 Leader 机械臂**：
   - 使用 USB 线将 Leader 机械臂连接到计算机
   - 确认端口号（默认为 `/dev/ttyUSB0`）

2. **连接 Follower 机械臂**：
   - 使用 USB 线将 Follower 机械臂连接到计算机
   - 确认端口号（默认为 `/dev/ttyUSB1`）

3. **检查 USB 设备**：

```bash
# 查看所有串口设备
ls -l /dev/ttyUSB*

# 如果没有权限，赋予读写权限
sudo chmod 777 /dev/ttyUSB*
```

---

## 📂 项目结构

```bash
python-sdk/
├── stararm102_ro.py       # 主从控制程序
└── PYTHON_SDK_GUIDE.md    # 本文档
```

---

## 💻 使用说明

### 基本使用

#### 1. 配置串口参数

编辑 `stararm102_ro.py` 文件，修改以下参数：

```python
SERVO_BAUDRATE = 1000000          # 舵机通信波特率
LEADER_PORT_NAME = "/dev/ttyUSB0" # Leader 机械臂端口号
FOLLOWER_PORT_NAME_Arr = ["/dev/ttyUSB1"]  # follower端口号
```

#### 2. 运行主从控制程序

```bash
# 赋予 USB 设备权限
sudo chmod 777 /dev/ttyUSB*

# 运行控制程序
python3 stararm102_ro.py
```

#### 3. 程序功能

程序启动后，将执行以下操作：

1. **初始化串口连接**：
   - 建立 Leader 机械臂的 UART 连接
   - 建立 Follower 机械臂的 UART 连接

2. **读取 Leader 状态**：
   - 实时读取 Leader 机械臂各关节角度
   - 支持 7 个舵机（ID: 0-6）

3. **控制 Follower 运动**：
   - 将 Leader 关节角度转换为 Follower 控制指令
   - 通过多圈角度间隔控制方式发送指令

4. **性能监控**：
   - 每秒显示当前运行频率（Hz）
   - 控制频率通常在 200Hz 左右

#### 4. 停止程序

按 `Ctrl+C` 终止程序运行

---

## 🔧 API 说明

### 主要函数

#### `main(args=None)`

主控制函数

**功能**：

- 初始化 Leader 和 Follower 串口连接
- 实时读取 Leader 关节角度
- 控制 Follower 跟随 Leader 运动
- 显示运行频率

**参数**：无

### 舵机控制参数

| 参数 | 值 | 说明 |
|---|-----|---|
| `SERVO_BAUDRATE` | 1000000 | 舵机通信波特率 |
| `LEADER_PORT_NAME` | /dev/ttyUSB0 | Leader 端口号 |
| `FOLLOWER_PORT_NAME` | /dev/ttyUSB1 | Follower 端口号 |
| `servo_ids` | [0,1,2,3,4,5,6] | 舵机 ID 列表 |

### Star Arm 102-HD 锁定功能按键板

Star Arm 102-HD 相比 LD 型号增加了一键锁定功能。按下锁定按键后，主臂会在当前姿态锁定，并让从臂同步进入锁定状态；再次按下按键后解除锁定。

#### 通过修改 `stararm102_ro.py` 开启按键功能

`stararm102_ro.py` 默认按照 Star Arm 102-LD 使用，不启用按键板。如果你使用的是 Star Arm 102-HD，需要编辑 `python-sdk/stararm102_ro.py`，在 `main(args)` 函数开头找到默认配置：

```python
# 默认（102LD）
button_enable = False
button_id = 7
filtered_size = 30
```

将 `button_enable` 改为 `True`：

```python
# Star Arm 102-HD
button_enable = True
button_id = 7
filtered_size = 30
```

保存后正常运行：

```bash
python3 stararm102_ro.py
```

按键板默认 ID 为 `7`。如果你的按键板 ID 不是 `7`，请同步修改 `button_id` 的值。

也可以不改源码，直接通过启动参数开启 HD 配置：

```bash
python3 stararm102_ro.py --leader_type 102HD
```

---

## 📊 控制流程

```bash
┌─────────────┐
│  Leader     │
│  机械臂      │
└──────┬──────┘
       │ 读取角度
       ▼
┌──────────────────┐
│   UART 串口通信   │
│ (/dev/ttyUSB0)   │
└──────┬───────────┘
       │
       ▼
┌──────────────────┐
│  Python 控制程序  │
│  - 数据处理       │
│  - 角度转换       │
└──────┬───────────┘
       │ 发送指令
       ▼
┌──────────────────┐
│   UART 串口通信   │
│ (/dev/ttyUSB1)   │
└──────┬───────────┘
       │
       ▼
┌─────────────┐
│  Follower   │
│  机械臂      │
└─────────────┘
```

---

## 🛡️ 安全注意事项

1. **操作前检查**：
   - 确保 USB 连接稳定
   - 确认机械臂周围无障碍物
   - 检查电源供电是否正常

2. **急停控制**：
   - 按 `Ctrl+C` 请求退出程序；这不是硬件急停
   - 如遇异常运动，应在保持安全距离的情况下关闭伺服电源；拔掉 USB 不保证停止运动

3. **关节限制**：
   - 确保 Leader 机械臂在安全角度范围内操作
   - 避免快速大幅度移动

4. **电源管理**：
   - 使用稳定的 12V 电源
   - 避免电压波动

---

## 🐛 故障排除

### 常见问题

**Q1: 找不到 `/dev/ttyUSB0` 设备？**

```bash
# 检查 USB 设备
ls -l /dev/ttyUSB*

# 检查 USB 设备信息
lsusb

# 查看串口日志
sudo dmesg | grep ttyUSB

# 如果被 brltty 占用，卸载它
sudo apt remove brltty

# 赋予权限
sudo chmod 777 /dev/ttyUSB*
```

**Q2: 串口连接失败？**

- 检查 USB 线是否松动
- 确认端口号是否正确
- 尝试更换 USB 端口
- 检查驱动是否正常安装

**Q3: 控制频率过低？**

- 检查串口通信是否正常
- 减少其他程序运行负载
- 使用 USB 3.0 端口以提高速度

**Q4: Follower 机械臂不跟随 Leader？**

- 检查 Follower 端口号配置
- 确认舵机 ID 设置正确
- 检查串口通信波特率

---

## 📖 详细文档

- [主项目 README](../README.zh.md) - 项目总览
- [ROS2 HUMBLE 使用文档](../ros2-humble/README.md) - ROS2 控制方式
- [Lerobot 使用文档](../lerobot/README.md) - Lerobot 框架集成

---

## 🔗 相关链接

- [FashionStar UART SDK](https://github.com/servodevelop/servo-uart-rs485-sdk/)
- [华馨京科技官网](https://fashionrobo.com/)

---

## 📄 许可证

各组件的许可证及待确认范围见 [许可证说明](../LICENSE.md)。

---

## 👥 致谢

- **感谢**：华馨京科技提供硬件支持和 SDK

---

**祝您使用愉快！如有问题，欢迎提交 Issue。**

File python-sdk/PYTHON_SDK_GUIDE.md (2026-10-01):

# Python teleoperation reference

For installation and the first run, use the [Python quick start](README.md). [Chinese supplementary guide](PYTHON_SDK_GUIDE.zh.md).

## Ports and options

| Option | Default | Meaning |
| --- | --- | --- |
| `--leader-port` | `/dev/ttyUSB2` | Leader serial port; always set explicitly for a new setup |
| `--follower-port` | `/dev/ttyUSB3` | FL port; repeat the option for multiple FL arms |
| `--leader-type` / `--leader_type` | `102LD` | `102LD` or `102HD` |
| `--button_enable` / `--button_disable` | Model-dependent | Override button handling; mutually exclusive |
| `--button true` / `--button false` | Model-dependent | Alternative button override |
| `--button_id` | `7` | Button board ID; separate from joint IDs 0–6 |
| `--filtered_size` | `1` | Moving-average window; positive integer |

The historical default ports are preserved for existing scripts. The quick start explicitly uses example ports USB0/USB1. Baud rate is `1,000,000` in `SERVO_BAUDRATE`.

## Control behavior

`main(args)` opens the selected serial ports, unlocks each arm, resets multi-turn counts, reads leader IDs 0–6, and sends targets to each FL. It applies a moving average to arm angles. The handle/gripper channel is multiplied by 1.5 and clamped to 0–90 degrees; it bypasses the moving average. A larger filter window adds lag.

This is a direct control example. It does not load a LeRobot calibration file, plan collision-free motion, or establish a new mechanical zero. Place both arms at the correct reference pose before launch. The hardware acceptance checks are listed in [validation](../docs/validation.md).

## HD button behavior

HD mode enables ID 7. The current script uses the board's reported lock state to lock leader joints 0–5 and unlock them when that state changes. The follower continues receiving angle targets; the gripper is not included in the leader joint-lock loop. This is different from the refactored LeRobot plugin's optional frozen-action behavior.

The button is a teleoperation control, not a hardware emergency stop. Confirm its behavior on your board revision before relying on it during a task.

## Communication helper

`check_connection.py` opens one serial port and pings selected IDs. It returns exit code `0` when all respond, `1` for missing responses, and `2` for invalid arguments or serial errors. It sends no torque, origin, or position commands.

## Other scripts

The directory retains experimental and setup scripts for compatibility. Read their serial-port constants and write operations before running them. Do not use a parameter-writing script to diagnose a missing USB connection.

[UART SDK source](https://github.com/servodevelop/servo-uart-rs485-sdk) · [Troubleshooting](../docs/troubleshooting.md)

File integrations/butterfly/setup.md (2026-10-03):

# Setup and first task

[Integration overview](README.md) · [Compatibility](compatibility.md) · [Troubleshooting](troubleshooting.md)

This is an orientation guide to the partner application. The referenced upstream deployment procedure has not yet been reproduced by Fashion Star.

## 1. Obtain the matching application revision

Clone the application into a separate directory, outside your Star Arm 102 checkout:

```bash
git clone https://github.com/butterfly-community/robot-arm.git butterfly-robot-arm
cd butterfly-robot-arm
git checkout --detach 08498c31c56cf339601851851225bf111f89c82d
```

This selects the documentation reference revision. It does not install dependencies or start the robot.

## 2. Prepare the upstream environment

Follow the matching [Docker deployment document](https://github.com/butterfly-community/robot-arm/blob/08498c31c56cf339601851851225bf111f89c82d/docs/DOCKER.md), including its build order, model assets, device configuration, and service settings. Configure a model service only if you want natural-language operation.

Keep credentials in the upstream local environment configuration. Use your host's actual network address rather than assuming that the example address in the partner documentation matches your machine. Its start command assumes service images have already been built.

## 3. Explore without hardware

Use the partner's documented software-only mode and supplied scene data first. Confirm that the browser can display the scene, select targets, and follow a planned task using virtual feedback. Confirm image and tool-call support before trying the natural-language interface.

This verifies application flow only. It does not validate camera calibration, physical contact, or grasp stability.

## 4. Connect a confirmed hardware configuration

After checking [compatibility](compatibility.md), follow the partner's device setup and [coordinate conventions](https://github.com/butterfly-community/robot-arm/blob/08498c31c56cf339601851851225bf111f89c82d/docs/STARARM-102.md). Check actual joint feedback and camera data before requesting motion. Run only the intended control application against the servo port.

Use the partner's camera-to-robot calibration process and the correct calibration-board dimensions. Recalibrate when the camera/robot mounting relationship changes. The process moves the arm; prepare a clear workspace and an accessible servo-power cutoff as described in the [hardware setup guide](../../docs/hardware-setup.md).

## 5. Try one pick-and-place task

Begin with one visible object and one clear destination. Inspect the selected target, planned motion, device feedback, and camera result. Once explicit page-based operation works, describe the same task through the natural-language interface.

Record the application revision, exact arm/camera configuration, calibration setup, and observed outcome. A completed chat response or software task status alone does not establish that the physical grasp succeeded.

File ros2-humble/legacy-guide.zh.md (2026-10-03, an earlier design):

> 历史资料归档，不再作为当前操作指南。请使用 [当前中文 README](README.zh.md)。

> 中文补充资料：保留原有使用说明。当前版本与英文入口中的兼容性说明为准。

# StarArm102 机械臂 - ROS2 MoveIt 使用教程
## StarArm102 Manipulator - ROS2 MoveIt Guide

<div align="center">
  StarArm102 Robotic Arm StarArm102
</div>

---

## 当前入口

本文件为原中文教程。安装、虚拟机械臂、实机连接和常见问题请优先查阅 [当前英文指南](README.md)。

## 🔧 环境依赖

### 系统要求

```bash
No LSB modules are available.

Distributor ID: Ubuntu
Description:    Ubuntu 22.04.5 LTS
Release:        22.04
Codename:       Jammy
ROS2:           Humble
```

---

## 📦 安装指南

### 1️⃣ 安装 ROS2 Humble

**中文指南：**
[ROS2 Humble 安装指南](https://wiki.seeedstudio.com/cn/install_ros2_humble/)

**English Guide：**
[ROS2 Humble Installation](https://wiki.seeedstudio.com/install_ros2_humble/)

### 2️⃣ 安装 MoveIt2

```bash
sudo apt install ros-humble-moveit*
```

### 3️⃣ 安装舵机 SDK 库

```bash
sudo pip install pyserial
sudo pip install fashionstar-uart-sdk
```

### 4️⃣ 克隆 StarArm102 功能包

```bash
cd ~/
git clone https://github.com/servodevelop/Star-Arm-102.git
cd ~/Star-Arm-102/ros2-humble
colcon build
echo "source ~/Star-Arm-102/ros2-humble/install/setup.bash" >> ~/.bashrc
source ~/.bashrc
```

> [!NOTE]
> 编译完成后，请执行 `source` 命令以使环境变量生效。
> After compilation, run `source` command to make environment variables take effect.

---

## 📦 功能包说明

| 功能包 | 说明 |
|---|---|
| `robo_driver` | 机械臂硬件驱动节点，负责与舵机通信 |
| `stararm102_description` | 机械臂URDF模型描述文件 |
| `stararm102_gazebo` | Gazebo仿真环境配置 |
| `stararm102_moveit_config` | MoveIt2运动规划配置 |
| `stararm102_controller` | 机械臂控制器节点 |
| `arm_moveit_read` | 位姿读取节点示例 |
| `arm_moveit_write` | 位姿写入节点示例 |
| `arm_read_pose` | 实时位姿读取节点 |
| `ros2_bag_recorder` | 示教轨迹录制与重播 |
| `robo_interfaces` | 自定义ROS2接口定义 |

---

## 🚀 MoveIt2 快速开始

### 🎮 使用虚拟机械臂

启动 RViz2 进行虚拟机械臂的路径规划和可视化控制。

**启动命令：**

```bash
ros2 launch stararm102_moveit_config demo.launch.py
```

启动后，您可以在 RViz2 界面中：

- 使用 **Motion Planning** 面板进行路径规划
- 拖动 **交互标记** 进行末端执行器定位
- 选择 **Planning Group** 来控制不同关节组
- 点击 **Plan** 查看规划路径
- 点击 **Execute** 执行规划轨迹

---

### 🦾 使用真实的机械臂

连接真实机械臂并进行实际控制。

**终端 1：启动手臂硬件驱动**

> [!IMPORTANT]
> 启动驱动后，手臂会移动到零位，请确保周围无障碍物。
> The arm will move to zero position after starting the driver. Ensure there are no obstacles nearby.

```bash
ros2 launch stararm102_moveit_config driver.launch.py
```

> [!TIP]
>
> - 如果serial出现问题可以运行
>
> ```bash
> sudo apt install --reinstall python3-serial
> ```

**终端 2**

**：启动 MoveIt2**

```bash
ros2 launch stararm102_moveit_config actual_robot_demo.launch.py
```

✅ 到此可实现虚拟机械臂控制真实机械臂的功能。
At this point, you can control the real robotic arm with the virtual robotic arm.

---

### 📐 手臂末端位姿读写示例

演示如何读取和写入机械臂末端的位姿信息。

**终端 3：启动末端位姿读写示例**

```bash
ros2 launch stararm102_moveit_config moveit_write_read.launch.py
```

该示例会：
- 实时显示当前末端执行器的位姿（位置和姿态）
- 演示如何设置目标位姿并执行运动
- 输出关节角度和笛卡尔坐标信息

---

### 📡 位姿话题发送节点示例

通过 ROS2 话题发送目标位姿，控制机械臂运动。

**终端 4：启动位姿话题发送节点**

```bash
# 运行话题发布节点
ros2 run arm_moveit_write topic_publisher
```

该节点会持续发布目标位姿到话题，MoveIt2 接收后控制机械臂运动到目标位置。

---

### 🎯 MoveIt2-Gazebo 仿真机械臂例程

在 Gazebo 物理仿真环境中测试机械臂控制。

> [!TIP]
> - 在关闭 Gazebo 图形界面后，建议使用 `pkill -9 -f gazebo` 命令彻底关闭
> - 运行例程前，需要关闭其他所有正在运行的节点
> - `killall -9 gazebo gzserver gzclient ros2`

#### 安装 Gazebo

```bash
sudo apt install gazebo
sudo apt install ros-humble-moveit*
sudo apt install -y ros-humble-gazebo-ros-pkgs ros-humble-gazebo-ros
```

#### 终端 1：启动 Gazebo 图形界面

```bash
ros2 launch stararm102_gazebo stararm102_gazebo.launch.py
```

启动 Gazebo 后，您会看到 StarArm102 机械臂在仿真环境中。

#### 终端 2：启动 MoveIt2 界面

```bash
ros2 launch stararm102_moveit_config gazebo_demo.launch.py
```

✅ 现在您可以在 RViz2 中进行路径规划，机械臂将在 Gazebo 仿真环境中执行运动。

---

## 🎓 机械臂示教模式

记录并重放机械臂的运动轨迹。

> [!TIP]
> - 需要重新录制轨迹时，可删除 `record-test` 文件夹或新建记录文件夹（如 `record-test1`）
> - 示教模式下，手臂驱动器需要解锁

### 终端 1：启动手臂硬件驱动（示教模式）

```bash
ros2 run robo_driver driver --ros-args -p lock:='disable'
```

> [!IMPORTANT]
> 设置 `lock:='disable'` 参数可以解锁关节，允许手动拖动机械臂进行示教。
> Setting `lock:='disable'` unlocks the joints, allowing manual dragging for teaching.

### 终端 2：记录手臂轨迹

按下回车开始录制，再次按下回车结束录制。通过 `dataset` 参数指定保存路径。

```bash
ros2 run ros2_bag_recorder bag_recorder --ros-args -p dataset:=star/record-test
```

**操作步骤：**

1. 运行命令后，按 **Enter** 开始录制
2. 手动拖动机械臂到目标位置
3. 完成后按 **Enter** 结束录制
4. 轨迹数据会保存到 `star/record-test` 文件夹

```bash
ros2 bag play ./star/record-test
```

机械臂会按照记录的轨迹自动运动。

> [!TIP]
>
> - 如果路径位置已经存在可以尝试删除旧路径`rm -rf star/record-test`或者更换新的路径如`dataset:=star/record-test2`

---

## 📊 关节配置

StarArm102 采用 6自由度机械臂 + 旋转夹爪：

| 关节 | 类型 | 角度范围 | 说明 |
|---|---|---|---|
| Joint1 | revolute | -110° ~ 110° | 底座旋转 |
| Joint2 | revolute | 0° ~ 180° | 肩部俯仰 |
| Joint3 | revolute | 0° ~ 270° | 肘部俯仰 |
| Joint4 | revolute | -90° ~ 90° | 手腕旋转 |
| Joint5 | revolute | -65° ~ 65° | 手腕俯仰 |
| Joint6 | revolute | -150° ~ 150° | 手腕偏航 |
| joint7_left | revolute | 0° ~ 90° | 旋转夹爪（主动） |
| joint7_right | revolute | -90° ~ 0° | 旋转夹爪（联动） |

> 📝 **旋转夹爪说明**：`joint7_right` 为 mimic 关节，自动与 `joint7_left` 反向同步。

---

## ❓ 常见问题 / FAQ

### RViz2 界面闪烁问题

如果 RViz2 界面出现频闪，可以尝试以下命令：

```bash
export QT_AUTO_SCREEN_SCALE_FACTOR=0
```

然后重新启动 RViz2。

### Gazebo 无法启动

如果 Gazebo 启动失败，请先检查是否有残留进程：

```bash
killall -9 gazebo gzserver gzclient 2>/dev/null || true
```

然后重新运行启动命令。

### 编译错误

如果在编译过程中遇到错误，请确保：

1. 已安装所有依赖：`sudo apt install ros-humble-moveit*`
2. 已正确 source ROS2 环境：`source /opt/ros/humble/setup.bash`
3. 在正确的目录下编译：`cd ~/Star-Arm-102/ros2-humble`

### 机械臂无法连接

如果机械臂无法连接，请检查：

1. USB 串口连接是否正常
2. 串口权限是否正确：`sudo chmod 666 /dev/ttyUSB0`
3. 舵机 SDK 是否已正确安装

### 示教轨迹重播不正常

如果示教轨迹重播时机械臂运动不正常：

1. 检查 URDF 配置是否正确
2. 确认 `joint7_left` 和 `joint7_right` 的 mimic 配置
3. 查看 joint_states 话题数据是否正确

---

## 📞 技术支持

如遇到问题，请访问：

- GitHub 仓库：[Star-Arm-102](https://github.com/servodevelop/Star-Arm-102)
- 提交 Issue 获取帮助

---

<div align="center">

**StarArm102 - 让机械臂控制更简单**

*StarArm102 - Making Robot Arm Control Simpler*

</div>

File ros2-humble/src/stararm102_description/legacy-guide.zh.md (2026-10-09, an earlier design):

> 历史资料归档，不再作为当前操作指南。请使用 [当前中文 README](README.zh.md)。

> 历史中文说明：当前入口为 [ROS 2 Humble 英文指南](../../README.md)，模型与关节定义以当前 URDF 为准。

# StarArm 102 ROS2 包

本目录包含 StarArm 102 机械臂的完整 ROS2 功能包。

## 包结构

### 1. stararm102_description ✅
机械臂描述包，包含 URDF 模型和 3D 网格文件。

- [URDF 与模型资源](README.zh.md) - 源文件位于当前包内，ROS 安装后的路径为 `urdf/star-arm-102.urdf`
- `meshes/` - 9 个共享显示／碰撞网格，构建时安装到 ROS 包内
- `launch/` - 启动文件
  - `display_rviz.launch.py` - RViz 可视化
  - `rviz_demo.launch.py` - 交互式 RViz 演示
  - `robo_state_publisher.launch.py` - 机器人状态发布器
- `rviz/` - RViz 配置文件

### 2. stararm102_controller ✅
机械臂控制器包，提供机械臂和夹爪的动作服务器。

- `stararm102_controller.py` - 控制器节点
- 支持机械臂轨迹控制 (FollowJointTrajectory)
- 支持夹爪控制 (GripperCommand)

### 3. stararm102_moveit_config ✅
MoveIt 运动规划配置包。

- `config/stararm102_description.srdf` - SRDF 语义描述
- `config/ros2_controllers.yaml` - 控制器配置
- `config/stararm102_description.ros2_control.xacro` - ros2_control 配置
- `config/stararm102_description.urdf.xacro` - URDF Xacro 文件
- `launch/demo.launch.py` - 演示启动文件
- `launch/rsp.launch.py` - 机器人状态发布器启动文件

### 4. stararm102_gazebo ✅
Gazebo 仿真包。

- `urdf/stararm102_gazebo.urdf` - Gazebo URDF 文件
- `urdf/gazebo_configs.urdf.xacro` - Gazebo 插件配置
- `config/stararm102_gazebo.urdf.xacro` - Gazebo Xacro 配置
- `launch/stararm102_gazebo.launch.py` - Gazebo 仿真启动文件
- `meshes/` - 3D 模型 STL 文件

## 快速开始

### 1. 查看所有包

```bash
cd /home/fsrobo/Star-Arm-102/ros2-humble
ls -l src/
```

应该看到以下包：
- stararm102_description
- stararm102_controller
- stararm102_moveit_config
- stararm102_gazebo

### 2. 编译项目

```bash
colcon build --packages-select stararm102_description
colcon build --packages-select stararm102_controller
colcon build --packages-select stararm102_moveit_config
colcon build --packages-select stararm102_gazebo
source install/setup.bash
```

### 3. 查看 URDF 模型

```bash
# 启动 RViz 查看机器人模型
ros2 launch stararm102_description display_rviz.launch.py

# 启动交互式 RViz 演示
ros2 launch stararm102_description rviz_demo.launch.py
```

### 4. 运行 Gazebo 仿真

```bash
# 启动 Gazebo 仿真
ros2 launch stararm102_gazebo stararm102_gazebo.launch.py
```

### 5. 运行控制器

```bash
# 启动机械臂控制器节点
ros2 run stararm102_controller stararm102_controller
```

### 6. 使用 MoveIt

```bash
# 启动 MoveIt 演示
ros2 launch stararm102_moveit_config demo.launch.py

# 启动机器人状态发布器
ros2 launch stararm102_moveit_config rsp.launch.py
```

## 关节名称

StarArm 102 机械臂有以下关节：

| 关节 | 名称 | 说明 |
|---|---|---|
| Joint1 | joint1 | 底座旋转 |
| Joint2 | joint2 | 肩部俯仰 |
| Joint3 | joint3 | 肘部俯仰 |
| Joint4 | joint4 | 手腕旋转 |
| Joint5 | joint5 | 手腕俯仰 |
| Joint6 | joint6 | 手腕偏航 |
| Gripper Left | joint7_left | 左夹爪 |
| Gripper Right | joint7_right | 右夹爪 |

## 关节角度限制

| 关节 | 下限 | 上限 | 单位 |
|---|---|---|---|
| joint1 | -2.27 | 2.27 | rad |
| joint2 | -1.57 | 1.57 | rad |
| joint3 | -1.57 | 1.57 | rad |
| joint4 | -1.57 | 1.57 | rad |
| joint5 | -1.57 | 1.57 | rad |
| joint6 | -2.27 | 2.27 | rad |
| joint7_left | -0.03 | 0 | m (prismatic) |

## 注意事项

1. ✅ URDF 文件中的包名已正确设置为 `stararm102_description`
2. ✅ 机器人名称已正确设置为 `stararm102`
3. ✅ Gazebo URDF 使用 file://$(find stararm102_gazebo) 路径
4. ✅ MoveIt 配置文件已创建
5. ⚠️ 控制器依赖于 `robo_interfaces` 包
6. ⚠️ MoveIt 的完整配置可能需要根据实际需求调整

## 后续工作

可以进一步完善的任务：

1. **MoveIt 配置优化**：
   - 添加 IK 解算器配置
   - 优化运动规划参数
   - 添加场景和物体定义

2. **Gazebo 配置增强**：
   - 添加更多物理属性
   - 配置传感器插件
   - 优化仿真性能

3. **测试与验证**：
   - 测试所有功能包
   - 验证运动规划
   - 测试仿真控制

4. **文档完善**：
   - 添加更多使用示例
   - 编写 API 文档
   - 添加故障排除指南

## 参考文档

- [MoveIt2 官方文档](https://moveit.picknik.ai/humble/)
- [ROS2 控制器文档](https://control.ros.org/)
- [Gazebo ROS2 文档](https://gazebosim.org/docs/all/ros2_components/)

## 作者

- 创建者：nyancos
- 基于 cello 和 viola 配置文件创建

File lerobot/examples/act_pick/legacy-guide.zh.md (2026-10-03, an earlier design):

> 历史资料归档，不再作为当前操作指南。请使用 [当前中文 README](README.zh.md)。

> 中文补充资料：保留原有使用说明。当前版本与英文入口中的兼容性说明为准。

# Star Arm 102 ACT 夹方块预训练模型

这是使用 LeRobot 训练的 Star Arm 102 方块放置策略。模型输入包含机械臂状态，以及两路 640 × 480 相机画面：`up`（上方视角）和 `front`（正面视角）。训练完成于 100,000 步。

下面直接列出客户需要执行的命令。动手前先看[训练场景摆放参考](#训练场景摆放参考)。可下载 [Word 版客户运行指南](docs/Star_Arm_102_ACT_客户运行指南.docx) 留存；完整模型在本仓库的 [act-pick-v1.0.0 Release](https://github.com/servodevelop/Star-Arm-102/releases/tag/act-pick-v1.0.0)。

## 下载和放置模型

在 Ubuntu 电脑上执行以下命令，下载并解压模型。压缩包约 191 MB：

```bash
curl -L -o stararm102_pick_act_torch271.tar.gz \
  https://github.com/servodevelop/Star-Arm-102/releases/download/act-pick-v1.0.0/stararm102_pick_act_torch271.tar.gz
mkdir -p ~/models/stararm102_pick_act_torch271
tar -xzf stararm102_pick_act_torch271.tar.gz -C ~/models/stararm102_pick_act_torch271
ls ~/models/stararm102_pick_act_torch271/pretrained_model
```

模型路径应为：

```text
~/models/stararm102_pick_act_torch271/pretrained_model
```

运行命令中的 `--policy.path` 要指向这个目录。目录内应包含 `config.json`、`model.safetensors`、`train_config.json` 和预处理器文件；请保留整个文件夹。

## 安装运行环境

已经有能运行 Star Arm 102 的 LeRobot 0.4.1 环境时，激活原环境即可。新电脑先安装 [Miniforge](https://github.com/conda-forge/miniforge#install)，重新打开终端，然后在 Ubuntu 22.04 上按下面的顺序安装 Python 3.10、LeRobot 和 Star Arm 102 插件：

```bash
conda create -n stararm102-act python=3.10 -y
conda activate stararm102-act
conda install -c conda-forge ffmpeg -y
python -m pip install "lerobot==0.4.1" \
  "lerobot-robot-stararm102==0.0.1" \
  "lerobot-teleoperator-stararm102==0.0.1"
```

训练机使用 RTX 5070 Ti，已验证的 PyTorch 组合为 `torch 2.7.1`、`torchvision 0.22.1`、`torchaudio 2.7.1` 的 CUDA 12.8 构建。客户也使用 RTX 50 系列 GPU 时，可以在同一个环境中运行：

```bash
python -m pip install torch==2.7.1 torchvision==0.22.1 torchaudio==2.7.1 \
  --index-url https://download.pytorch.org/whl/cu128
python -m pip check
python -c "import torch; print(torch.__version__, torch.cuda.is_available()); print(torch.cuda.get_device_name(0) if torch.cuda.is_available() else 'CPU')"
```

其他显卡请在 [PyTorch 官方安装页面](https://pytorch.org/get-started/locally/) 选择适合的构建。`torch` 应保持在 LeRobot 0.4.1 支持的范围内。安装完成后，运行 `lerobot-record --help` 确认命令可用。

## 检查设备并校准

接好 Star Arm 102 从臂和两台相机，检查实际设备名：

```bash
ls -l /dev/ttyUSB*
lerobot-find-cameras opencv
```

下面示例假设从臂是 `/dev/ttyUSB1`，上方相机是 `/dev/video0`，正面相机是 `/dev/video1`。两台相机的序号可能因电脑或 USB 插口而改变。要确认画面内容，使 `up` 对应上方视角、`front` 对应正面视角；模型输入的这两个名称保持不变。

首次使用从臂时，先按 Star Arm 102 的校准流程完成校准。使用本页示例 ID 的命令为：

```bash
lerobot-calibrate \
  --robot.type=lerobot_robot_stararm102 \
  --robot.port=/dev/ttyUSB1 \
  --robot.id=customer_stararm102_follower
```

校准后在运行模型时继续使用同一个 `--robot.id`。启动策略前，固定底座，清空机械臂工作范围，并准备好硬件急停。桌面、相机位置、光照和方块区域应尽量接近训练示范。

## 训练场景摆放参考

采集示范或运行模型前，请参照以下三张照片摆放相机支架、Star Arm 102 从臂和操作垫。固定相机朝向、机械臂底座与操作垫的相对位置；让 `up` 和 `front` 两路画面都能清楚拍到训练工作区。照片提供的是位置与视角参考，没有标注精确距离，最终以两路实时画面和实际训练示范为准。

侧面总览：相机支架在操作垫左侧，从臂固定在右侧，镜头朝向操作区域。

训练场景侧面总览：左侧相机支架、右侧 Star Arm 102 从臂与操作垫

斜侧视角：检查机械臂、操作垫和红色方块的相对位置；方块放在训练示范覆盖的起始区域。

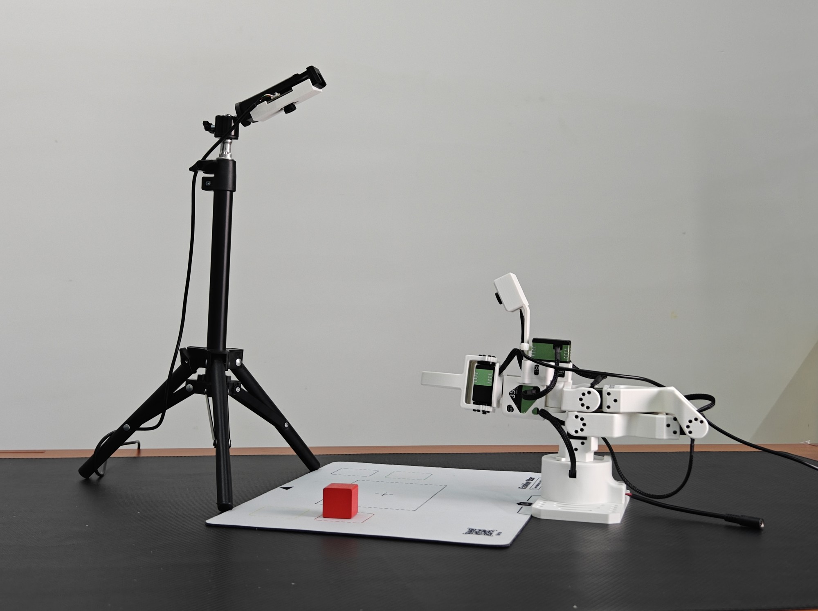
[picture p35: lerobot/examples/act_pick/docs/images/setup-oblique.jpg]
训练场景斜侧视角：机械臂、相机支架、操作垫及方块


正面视角：检查相机支架与机械臂的前后关系，并确认方块区域没有被机械臂底座遮挡。

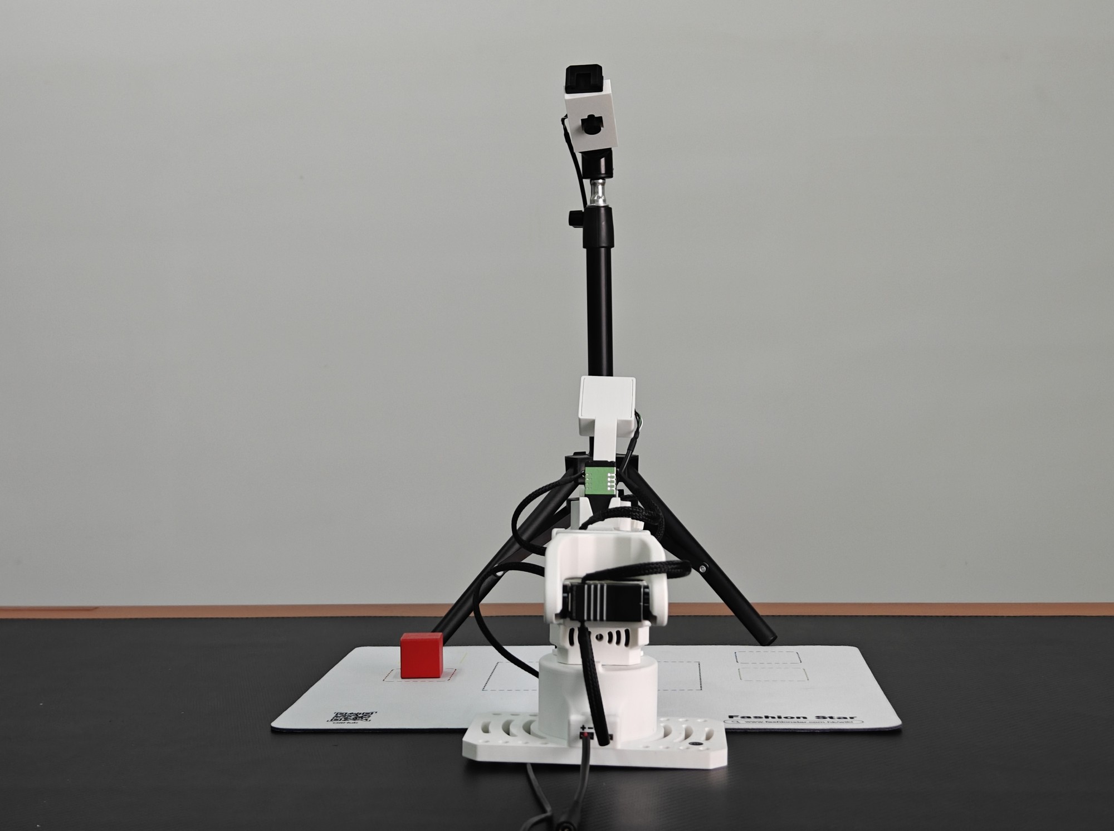
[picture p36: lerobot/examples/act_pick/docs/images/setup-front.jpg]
训练场景正面视角：机械臂位于操作垫前方，相机支架位于后方


每次采集或评估前，核对两路相机画面没有对调、镜头没有明显偏转，并将方块放在训练数据包含的位置范围内。照片中的方块位置只是摆放示例；不要据此推断单一固定坐标。

## 训练完成后的现场视频

点击下方播放器即可在线观看。请结合上方三张照片核对设备摆位，再进行数据采集或模型验证。

https://github.com/user-attachments/assets/6774384d-f437-4aa9-a364-cd66eba965f7

[下载原视频（MP4，约 61 MB）](https://github.com/servodevelop/Star-Arm-102/releases/download/act-pick-v1.0.0/stararm102_act_trained_demo.mp4)

## 单组验证示例

修改命令中的从臂串口和两台相机路径后，先运行 1 组：

```bash
lerobot-record \
  --robot.type=lerobot_robot_stararm102 \
  --robot.port=/dev/ttyUSB1 \
  --robot.id=customer_stararm102_follower \
  --robot.cameras='{up: {type: opencv, index_or_path: /dev/video0, width: 640, height: 480, fps: 30}, front: {type: opencv, index_or_path: /dev/video1, width: 640, height: 480, fps: 30}}' \
  --policy.path="$HOME/models/stararm102_pick_act_torch271/pretrained_model" \
  --display_data=true \
  --dataset.repo_id=customer/eval_stararm102_pick_run1 \
  --dataset.root="$HOME/lerobot_data/eval_stararm102_pick_run1" \
  --dataset.num_episodes=1 \
  --dataset.episode_time_s=30 \
  --dataset.reset_time_s=10 \
  --dataset.single_task="将方块放入中心" \
  --dataset.push_to_hub=false
```

该命令会驱动从臂并保存一次本地评估记录。观察机械臂的动作方向、速度和任务结果；异常时立即急停。

## 连续验证 10 组

确认单组运行正常后，可连接主臂用于组间复位，并运行 10 组。下面命令假设主臂串口是 `/dev/ttyUSB0`；执行前按实际设备修改：

```bash
lerobot-record \
  --robot.type=lerobot_robot_stararm102 \
  --robot.port=/dev/ttyUSB1 \
  --robot.id=customer_stararm102_follower \
  --robot.cameras='{up: {type: opencv, index_or_path: /dev/video0, width: 640, height: 480, fps: 30}, front: {type: opencv, index_or_path: /dev/video1, width: 640, height: 480, fps: 30}}' \
  --teleop.type=lerobot_teleoperator_stararm102 \
  --teleop.port=/dev/ttyUSB0 \
  --teleop.id=customer_stararm102_leader \
  --policy.path="$HOME/models/stararm102_pick_act_torch271/pretrained_model" \
  --display_data=true \
  --dataset.repo_id=customer/eval_stararm102_pick_run10 \
  --dataset.root="$HOME/lerobot_data/eval_stararm102_pick_run10" \
  --dataset.num_episodes=10 \
  --dataset.episode_time_s=30 \
  --dataset.reset_time_s=10 \
  --dataset.single_task="将方块放入中心" \
  --dataset.push_to_hub=false
```

每组结束后有 10 秒复位时间，可在此期间重新放置方块。若不使用主臂，从命令中删除连续三行 `--teleop.*`，并在下一组开始前检查从臂的起始姿态。每次重新运行评估，都给 `--dataset.repo_id` 和 `--dataset.root` 使用新的名称和目录。

## 哪些参数需要改

| 参数 | 客户操作 |
| --- | --- |
| `--robot.port` | 改为从臂实际串口，通常是 `/dev/ttyUSB*`。 |
| `--robot.id` | 与从臂校准时使用的 ID 保持一致。 |
| `--robot.cameras` | 修改两台相机的 `index_or_path`；保留 `up` 和 `front` 名称，以及 640 × 480 分辨率。 |
| `--policy.path` | 指向解压后的 `pretrained_model` 文件夹，不是上一级目录或单个权重文件。 |
| `--dataset.repo_id` | 本次评估记录的名称；每次新运行用新名称。 |
| `--dataset.root` | 本地评估数据保存位置；每次新运行用未存在的新目录。 |
| `--dataset.num_episodes` | 评估组数，先用 `1`，稳定后可改为 `10`。 |
| `--dataset.episode_time_s` | 每组最长运行时间，示例为 30 秒。 |
| `--dataset.reset_time_s` | 两组之间的复位等待时间，示例为 10 秒。 |
| `--teleop.port` | 仅在接主臂做组间复位时添加，改为主臂实际串口。 |

这些参数在运行命令里修改，客户不需要为更换串口或相机路径而编辑模型文件。`--dataset.push_to_hub=false` 表示评估数据只保存在本机。

## 常见问题

- 相机打不开：重新运行 `lerobot-find-cameras opencv`，检查视频画面及设备路径。
- 模型加载失败：检查 `--policy.path` 是否指向包含 `config.json` 和 `model.safetensors` 的 `pretrained_model` 目录。
- 提示没有校准文件：先完成从臂校准，并保持同一个 `--robot.id`。
- 提示数据目录已存在：换一个新的 `--dataset.root` 和 `--dataset.repo_id`。
- 组间出现无 teleop 的提示：如需主臂复位，加入上面的三项 `--teleop.*`；否则手动确认下一组的起始姿态。
- 动作表现不稳定：核对 `up`/`front` 画面是否交换，以及相机位置、物体、光照和起始姿态是否接近训练示范。

模型模仿的是“将方块放入中心”这一项任务。它不会自行判断新物体何时放入，也不会无限次自动重启；运行组数由 `--dataset.num_episodes` 控制。

## 模型信息

| 项目 | 值 |
| --- | --- |
| 策略 | ACT |
| 任务 | 将方块放入中心 |
| 训练步数 | 100,000 |
| 输入 | 7 维机械臂状态；`up` 和 `front` 两路 RGB 画面 |
| 输出 | 7 维动作 |
| 相机规格 | 640 × 480，30 FPS |
| 模型包 | `stararm102_pick_act_torch271.tar.gz`，191,108,326 字节 |

模型适用于训练示范覆盖的任务和工作范围；部署前请完成实机验证。

## 相关资料

- [Star Arm 102 LeRobot 官方教程](../../stararm102.md)
- [PyTorch 官方安装页面](https://pytorch.org/get-started/locally/)

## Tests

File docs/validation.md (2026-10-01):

# Validation record and hardware handoff

This page separates checks performed during the English-first update from checks that require a robot, cameras, GPU, or ROS host.

## Software and document checks

- Seven Python entry tests pass on Python 3.12, covering ping-only communication, missing devices, serial failures, resource closure, CLI validation, backwards-compatible option spelling, and help without hardware access.
- The local Markdown checker passes for all 38 Markdown files, including Chinese supplementary material. It does not verify remote services or heading fragments; customer-path heading links were reviewed separately.
- All repository Python files parse successfully without executing hardware control. The 38 shell snippets in the main English customer guides pass `bash -n`; this checks syntax, not hardware behavior. Git diff whitespace and the new workflow/issue-form YAML were also checked.
- Dependency resolution succeeds for Linux x86-64 / Python 3.10 with LeRobot 0.4.1, both StarArm plugins 0.0.1, torch/torchaudio 2.7.1, and torchvision 0.22.1. The resolver selected motor plugin 0.0.7. This was a metadata resolution check against PyPI, not installation of the CUDA 12.8 wheels or execution on Ubuntu.
- In separate macOS / Python 3.12 environments, dependency checks pass for both plugin generations. The release-compatible 0.0.1 plugins register successfully, and `lerobot-record --help` exposes their device types with motor plugin 0.0.6 and 0.0.7.
- The refactored package installs with LeRobot 0.4.1 and motor plugin 0.0.6; `lerobot-teleoperate --help` exposes `stararm102_hd` and `stararm102_fl` after a regular install. A default editable install did not expose them, so the guides now use regular installation. CLI checks used a dummy keyboard backend and opened no robot ports.
- The published ACT archive was downloaded and its SHA-256 matched `SHA256SUMS.txt`: `9d1b5272174ea2595badfa7362ae67bea5c8e1ec30137b1d46dcd21d30f27931` (191,108,326 bytes).
- Its configuration confirms seven state/action dimensions, `up` and `front` images at 3 × 480 × 640, CUDA as the saved device, and a 100,000-step training configuration. Download integrity and metadata checks do not establish inference performance.

Re-run the automated checks using [CONTRIBUTING.md](../CONTRIBUTING.md#check-a-change). Hardware validation was not performed during this documentation update.

## Before declaring a customer setup validated

Record the arm models/revisions, firmware if identifiable, OS, repository commit, package versions, camera models, and GPU/driver. Complete only the applicable path:

| Path | Acceptance check | Current status |
| --- | --- | --- |
| Wiring and reference pose | Confirm power/connector labels and provide revision-specific LD/HD/FL zero-pose photographs | Needs hardware owner confirmation |
| Python LD → FL | IDs 0–6 respond; small motions and gripper track correctly; stop behavior understood | Bench test required |
| Python HD → FL | Above, plus ID 7 and actual lock/unlock behavior | Bench test required |
| Release-compatible LeRobot | Calibration saved/reused and seven-channel motion checked | Bench test required |
| Refactored HD/FL | Calibration, directions, ranges, and button behavior | CLI discovery passed; bench test required |
| ACT | Clean Ubuntu/GPU installation; both camera views; one supervised task; saved local episode; repeat-trial results | Customer environment and bench test required |
| ROS 2 Humble | Clean build; RViz virtual plan; real driver initialization; small executed trajectory | ROS host and bench test required |
| reBot | Exact upstream version and supported leader/button combination | Upstream integration test required |

For ACT, count attempts and successes with a stated scene and criterion before publishing a success rate. For the direct Python path, a verified reference-pose illustration is still needed; do not invent one from a different arm's photo.

## Maintainer decisions still needed

Confirm the intended license for original code, documents, hardware designs, media, and model weights. Existing component licenses remain in place; [LICENSE.md](../LICENSE.md) records the current gaps.

The detailed bilingual Wiki course, model/dataset publishing strategy, and a tested end-to-end training curriculum remain the second phase.

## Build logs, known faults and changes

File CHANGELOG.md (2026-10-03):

# Changelog

## Unreleased — English-first customer entry

- Audit coverage against previous main, restore nested ignore rules and the refactored LeRobot checkpoint evaluation entry, and record migration validation and remaining gaps in `docs/main-migration-review.md`.

- Align all eight existing bilingual README pairs; archive older Chinese guides, remove the redundant root README_zh.md redirect, and add bilingual maintenance rules and structural CI checks.

- Add cross-brand pairing navigation for Galaxea A1, Lumos Touch, YAM, and Seeed reBot; separate documented upstream paths from pending setup and validation records. Move the reBot guide into `integrations/` while preserving its old documentation link.

- Add a Wiki-linked robot and servo tool directory with a web interface preview; move repository documentation checks to `scripts/` and update workflow commands.

- Add an English homepage with setup selection, a prominent ACT model entry, demo, and official product links.
- Add first-use, wiring, compatibility, troubleshooting, and joint-mapping guides.
- Provide English Python, LeRobot, ACT inference, ROS 2, and hardware navigation; preserve Chinese supplementary material.
- Separate the release-compatible ACT plugins from the refactored HD/FL environment.
- Add explicit serial-port options and a ping-only communication check to the Python examples.
- Correct HD button examples, plugin import names, conflicting dataset paths, and unsafe stopping descriptions. Use regular plugin installation so LeRobot 0.4.1 can discover device types.
- Add issue templates and automated documentation/CLI checks. Record physical verification separately.

- Standardize top-level resource and workspace paths as `hardware/`, `media/`, `lerobot/`, `python-sdk/`, and `ros2-humble/`; update documentation, tests, and workflow commands to match.

Python module names, ROS package identifiers, model assets, and release URLs are retained. Existing external links to renamed directories need updating. License scope still requires maintainer clarification for resources without a complete license declaration.

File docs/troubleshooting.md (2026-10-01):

# Troubleshooting and support

[Get started](getting-started.md) · [Compatibility](compatibility.md)

Stop at the first failing step. Check communication before calibration, motion before cameras, and camera images before running a policy.

| Symptom | Check | Expected result |
| --- | --- | --- |
| No serial device | USB data cable, power, one arm at a time; `python -m serial.tools.list_ports -v` | A port appears/disappears with that arm |
| Permission denied | Ubuntu `dialout` membership; log in again after adding the group | Port opens without running the application as root |
| Port busy | Close other control apps, serial monitors, and previous robot sessions | One process controls each bus |
| A servo ID is missing | Correct arm power, cable chain, IDs 0–6, 1,000,000 baud | Communication check lists all seven IDs |
| Button ID 7 not found | HD board present, correct mode/firmware; LD must not enable it | HD board responds, or button mode is disabled for a deliberate non-button test |
| Follower jumps or moves in the wrong direction | Stop; check leader/follower port assignment, zero/reference pose, plugin generation and calibration | Small movements track correctly before full teleoperation |
| Unknown LeRobot robot/teleoperator type | Active environment, a regular (not default editable) package install, and [type names](compatibility.md) | The selected type is registered by the installed plugin |
| Import fails after installing the HD package | Two packages share one import name | Recreate separate ACT and HD environments |
| Camera fails or views are swapped | Run `lerobot-find-cameras opencv`; inspect the images after reconnecting USB | `up` is overhead and `front` is frontal for the supplied ACT policy |
| ACT model cannot load | Point `--policy.path` to the full `pretrained_model` directory | Config, weights and processor files are together |
| Calibration not found | Use the same `--robot.id` and environment used during calibration | Correct file loads for that device |
| Dataset directory already exists | Choose a new `--dataset.root` and matching repo ID | A fresh run is saved without deleting previous recordings |
| Policy moves poorly | Compare the camera placement, scene, lighting, object and initial pose with the demo | Validate one trial before increasing the number of episodes |

If serial devices disappear unexpectedly, inspect system logs for the adapter and any service claiming it. Only change services such as `brltty` after confirming a conflict; it may be needed for an accessibility device.

## Report a problem

Use the [English issue form](https://github.com/servodevelop/Star-Arm-102/issues/new/choose). Include:

- Arm model(s), hardware revision and connection diagram/photo.
- OS, Python version, selected guide and repository commit.
- Package versions (`python -m pip freeze`) and GPU details for ACT.
- Exact command, full error, expected result, and first step that fails.
- Whether communication, calibration and basic motion each passed.

Remove access tokens and private paths from logs. For order-specific matters, contact the seller through your order channel and refer to the [official series page](https://fashionstar.com.hk/robot-arm/star-arm-102/).

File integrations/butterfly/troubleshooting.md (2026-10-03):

# Butterfly integration troubleshooting

[Integration overview](README.md) · [Setup](setup.md) · [Compatibility](compatibility.md)

| Symptom | First checks |
| --- | --- |
| Application does not start | Confirm the reference revision, required assets, image build order, and service logs against the upstream deployment guide. |
| Browser page cannot connect | Check the actual host address and exposed ports. The upstream documentation's example IP is not a universal address. |
| Page controls work but natural-language tasks fail | Check model endpoint, credentials, image input, and tool-call support; inspect the provider/application error. |
| Camera is unavailable or localization is wrong | Check device passthrough, selected stream, aligned depth, calibration-board dimensions, and the current camera-to-robot transform. |
| Servo port is unavailable | Check USB access and port selection, and close other programs using the same port. |
| Displayed joints or motion do not match the arm | Stop issuing movement requests. Check exact hardware, servo models, zero conventions, and the partner's pinned model and patches before retrying. |
| Software reports completion but the object was not moved correctly | Inspect the camera result, target selection, calibration, grasp, and execution feedback separately. Software-only mode cannot validate physical grip. |

For application-specific details, use the matching [deployment guide](https://github.com/butterfly-community/robot-arm/blob/08498c31c56cf339601851851225bf111f89c82d/docs/DOCKER.md) and [device guide](https://github.com/butterfly-community/robot-arm/blob/08498c31c56cf339601851851225bf111f89c82d/docs/STARARM-102.md).

For support, provide the upstream commit, arm model/revision, installed servo models, camera, host environment, simulated/physical mode, and relevant logs without credentials. Application questions belong in the [partner issue tracker](https://github.com/butterfly-community/robot-arm/issues); Star Arm 102 product questions can use [our support entry](../../README.md#documentation-and-support).

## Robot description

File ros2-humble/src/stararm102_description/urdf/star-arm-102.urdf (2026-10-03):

<?xml version="1.0" encoding="utf-8"?>
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
<robot name="stararm102_description">
      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
  <link name="world"/>

  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
  <joint name="world_to_base" type="fixed">
    <parent link="world"/>
    <child link="base_link"/>
    <origin xyz="0 0 0" rpy="0 0 0"/>
  </joint>
  <link name="base_link">
    <inertial>
      <origin xyz="-0.00507886641574018 -3.42055196168034E-05 0.0170541570471663" rpy="0 0 0" />
      <mass value="0.155441639095221" />
      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
    </inertial>
    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
  </link>
  <link name="link1">
    <inertial>
      <origin xyz="-0.000860795817551681 3.48041004087085E-05 0.0388877617080775" rpy="0 0 0" />
      <mass value="0.0365919096309897" />
      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
    </inertial>
    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
  </link>
  <joint name="joint1" type="revolute">
    <origin xyz="0 0 0.0283500000000012" rpy="0 0 0" />
    <parent link="base_link" />
    <child link="link1" />
    <axis xyz="0 0 -1" />
    <limit lower="-2.27" upper="2.27" effort="100" velocity="1" />
  </joint>
  <link name="link2">
    <inertial>
      <origin xyz="0.065445114144764 4.80766137382835E-05 1.86081119329107E-05" rpy="0 0 0" />
      <mass value="0.0677741447743621" />
      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
    </inertial>
    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
  </link>
  <joint name="joint2" type="revolute">
    <origin xyz="0.000100000000001007 0 0.0620250000000017" rpy="-1.5707963267949 0 3.14159265358979" />
    <parent link="link1" />
    <child link="link2" />
    <axis xyz="0 0 -1" />
    <limit lower="0" upper="3.14" effort="100" velocity="1" />
  </joint>
  <link name="link3">
    <inertial>
      <origin xyz="0.0139670047463857 -0.0548362979855048 -0.0260232297832349" rpy="0 0 0" />
      <mass value="0.062483417986533" />
      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
    </inertial>
    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
  </link>
  <joint name="joint3" type="revolute">
    <origin xyz="0.120565306190578 -0.0100999999999999 0.0259999999999978" rpy="0 0 -1.5707963267949" />
    <parent link="link2" />
    <child link="link3" />
    <axis xyz="0 0 -1" />
   <limit lower="-3.14" upper="0" effort="100" velocity="1" />
  </joint>
  <link name="link4">
    <inertial>
      <origin xyz="0.0233852853653051 -0.00064950134956597 -4.72632631462466E-06" rpy="0 0 0" />
      <mass value="0.0290020616470162" />
       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
    </inertial>
    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
  </link>
  <joint name="joint4" type="revolute">
    <origin xyz="0.0162194771204603 -0.107604056191361 -0.0259999999999976" rpy="0 0 -1.5707963267949" />
    <parent link="link3" />
    <child link="link4" />
    <axis xyz="0 0 -1" />
    <limit lower="-1.57" upper="2.2" effort="100" velocity="1" />
  </joint>
  <link name="link5">
    <inertial>
      <origin xyz="0.0239721333681056 1.60405714164091E-06 0.0123439857182104" rpy="0 0 0" />
      <mass value="0.04381347428302" />
      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
    </inertial>
    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
  </link>
  <joint name="joint5" type="revolute">
    <origin xyz="0.0350000000000005 -0.0013799999999997 0" rpy="-1.57079632679489 0 0" />
    <parent link="link4" />
    <child link="link5" />
    <axis xyz="0 0 -1" />
    <limit lower="-1.2" upper="1.2" effort="100" velocity="1" />
  </joint>
  <link name="link6">
    <inertial>
      <origin xyz="0.00415459393144704 6.90476927523165E-05 -0.0776167187492962" rpy="0 0 0" />
      <mass value="0.0277279215984807" />
      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
    </inertial>
    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
  </link>
  <joint name="joint6" type="revolute">
    <origin xyz="0.15168 0 0.005225" rpy="-1.5708 0 -1.5708" />
    <parent link="link5" />
    <child link="link6" />
    <axis xyz="0 0 -1" />
    <limit lower="-3.14" upper="3.14" effort="100" velocity="1" />
  </joint>
  <link name="link7_left">
    <inertial>
      <origin xyz="0.0281158042585857 0.00012184612342972 0.000226777556244492" rpy="0 0 0" />
      <mass value="0.0209012827567763" />
      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
    </inertial>
    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
  </link>
  <joint name="joint7_left" type="revolute">
    <origin xyz="0.012325 0 -0.07313" rpy="1.5708 -1.5708 0" />
    <parent link="link6" />
    <child link="link7_left" />
    <axis xyz="0 0 -1" />
    <limit lower="0" upper="1.57" effort="5" velocity="3.14" />
  </joint>
  <link name="link7_right">
    <inertial>
      <origin xyz="0.029631 -9.0637E-05 -0.0004" rpy="0 0 0" />
      <mass value="0.019895" />
      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
    </inertial>
    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
  </link>
  <joint name="joint7_right" type="revolute">
   <origin xyz="-0.009675 0 -0.07313" rpy="1.5708 -1.5708 0" />
    <parent link="link6" />
    <child link="link7_right" />
    <axis xyz="0 0 -1" />
    <limit lower="-1.57" upper="0" effort="5" velocity="3.14" />
    <mimic joint="joint7_left" multiplier="-1" />
  </joint>
</robot>

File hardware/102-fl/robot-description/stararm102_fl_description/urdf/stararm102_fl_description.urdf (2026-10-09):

<?xml version="1.0" encoding="utf-8"?>
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
<robot name="stararm102_fl_description">
  <link name="base_link">
    <inertial>
      <origin xyz="-0.00667834253031468 -0.00417660563990577 0.0111466998783985" rpy="0 0 0" />
      <mass value="0.174549702414155" />
      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
    </inertial>
    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
  </link>
  <link name="link1">
    <inertial>
      <origin xyz="-0.000852691744796436 3.44764229769992E-05 0.0377475507078772" rpy="0 0 0" />
      <mass value="0.0369396936287028" />
      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
    </inertial>
    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
  </link>
  <joint name="joint1" type="revolute">
    <origin xyz="0 -0.004138 0.02785" rpy="0 0 0" />
    <parent link="base_link" />
    <child link="link1" />
    <axis xyz="0 0 -1" />
    <limit lower="-2.27" upper="2.27" effort="100" velocity="1" />
  </joint>
  <link name="link2">
    <inertial>
      <origin xyz="0.0657767013029727 4.83058442201506E-05 1.86969634896764E-05" rpy="0 0 0" />
      <mass value="0.0674524422582712" />
      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
    </inertial>
    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
  </link>
  <joint name="joint2" type="revolute">
    <origin xyz="0.0001 0 0.061025" rpy="-1.5708 0 3.1416" />
    <parent link="link1" />
    <child link="link2" />
    <axis xyz="0 0 -1" />
    <limit lower="-1.57" upper="1.57" effort="100" velocity="1" />
  </joint>
  <link name="link3">
    <inertial>
      <origin xyz="0.0219670047638833 -0.0558862979532862 -2.32297530552865E-05" rpy="0 0 0" />
      <mass value="0.0624834178895674" />
      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
    </inertial>
    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
  </link>
  <joint name="joint3" type="revolute">
    <origin xyz="0.12162 -0.0021 0" rpy="0 0 -1.5708" />
    <parent link="link2" />
    <child link="link3" />
    <axis xyz="0 0 -1" />
    <limit lower="-1.57" upper="1.57" effort="100" velocity="1" />
  </joint>
  <link name="link4">
    <inertial>
      <origin xyz="0.0229484355874225 -0.000688761609614966 -5.46336290551225E-06" rpy="0 0 0" />
      <mass value="0.0314575373042392" />
      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
    </inertial>
    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
  </link>
  <joint name="joint4" type="revolute">
    <origin xyz="0.024219 -0.10865 0" rpy="0 0 -1.5708" />
    <parent link="link3" />
    <child link="link4" />
    <axis xyz="0 0 1" />
    <limit lower="-1.57" upper="1.57" effort="100" velocity="1" />
  </joint>
  <link name="link5">
    <inertial>
      <origin xyz="0.0239721333681058 1.60405714180919E-06 0.00974398571821249" rpy="0 0 0" />
      <mass value="0.0438134742830199" />
      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
    </inertial>
    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
  </link>
  <joint name="joint5" type="revolute">
    <origin xyz="0.035 0.00122 0" rpy="-1.5708 0 0" />
    <parent link="link4" />
    <child link="link5" />
    <axis xyz="0 0 -1" />
    <limit lower="-2.27" upper="2.27" effort="100" velocity="1" />
  </joint>
  <link name="link6">
    <inertial>
      <origin xyz="0.00427291306576536 0.00025827659516546 -0.0775271903843125" rpy="0 0 0" />
      <mass value="0.0274618030807584" />
      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
    </inertial>
    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
  </link>
  <joint name="joint6" type="revolute">
    <origin xyz="0.15168 0 0.002625" rpy="-1.5708 0 -1.5708" />
    <parent link="link5" />
    <child link="link6" />
    <axis xyz="0 0 -1" />
    <limit lower="-2.27" upper="2.27" effort="100" velocity="1" />
  </joint>
  <link name="link7_left">
    <inertial>
      <origin xyz="0.0281158042585856 0.000121846123429721 0.000126777556244531" rpy="0 0 0" />
      <mass value="0.0209012827567763" />
      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
    </inertial>
    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
  </link>
  <joint name="joint7_left" type="revolute">
    <origin xyz="0.012325 0.0004 -0.07313" rpy="1.5708 -1.5708 0" />
    <parent link="link6" />
    <child link="link7_left" />
    <axis xyz="0 0 1" />
    <limit lower="-2.27" upper="2.27" effort="100" velocity="1" />
  </joint>
  <link name="link7_right">
    <inertial>
      <origin xyz="0.0296744564241079 -9.10791758051248E-05 0.000248475512152638" rpy="0 0 0" />
      <mass value="0.0197986896996923" />
      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
    </inertial>
    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
  </link>
  <joint name="joint7_right" type="revolute">
    <origin xyz="-0.009675 0.0004 -0.07313" rpy="1.5708 -1.5708 0" />
    <parent link="link6" />
    <child link="link7_right" />
    <axis xyz="0 0 1" />
    <limit lower="-2.27" upper="2.27" effort="100" velocity="1" />
      <mimic joint="joint7_left" multiplier="-1" />
  </joint>
</robot>

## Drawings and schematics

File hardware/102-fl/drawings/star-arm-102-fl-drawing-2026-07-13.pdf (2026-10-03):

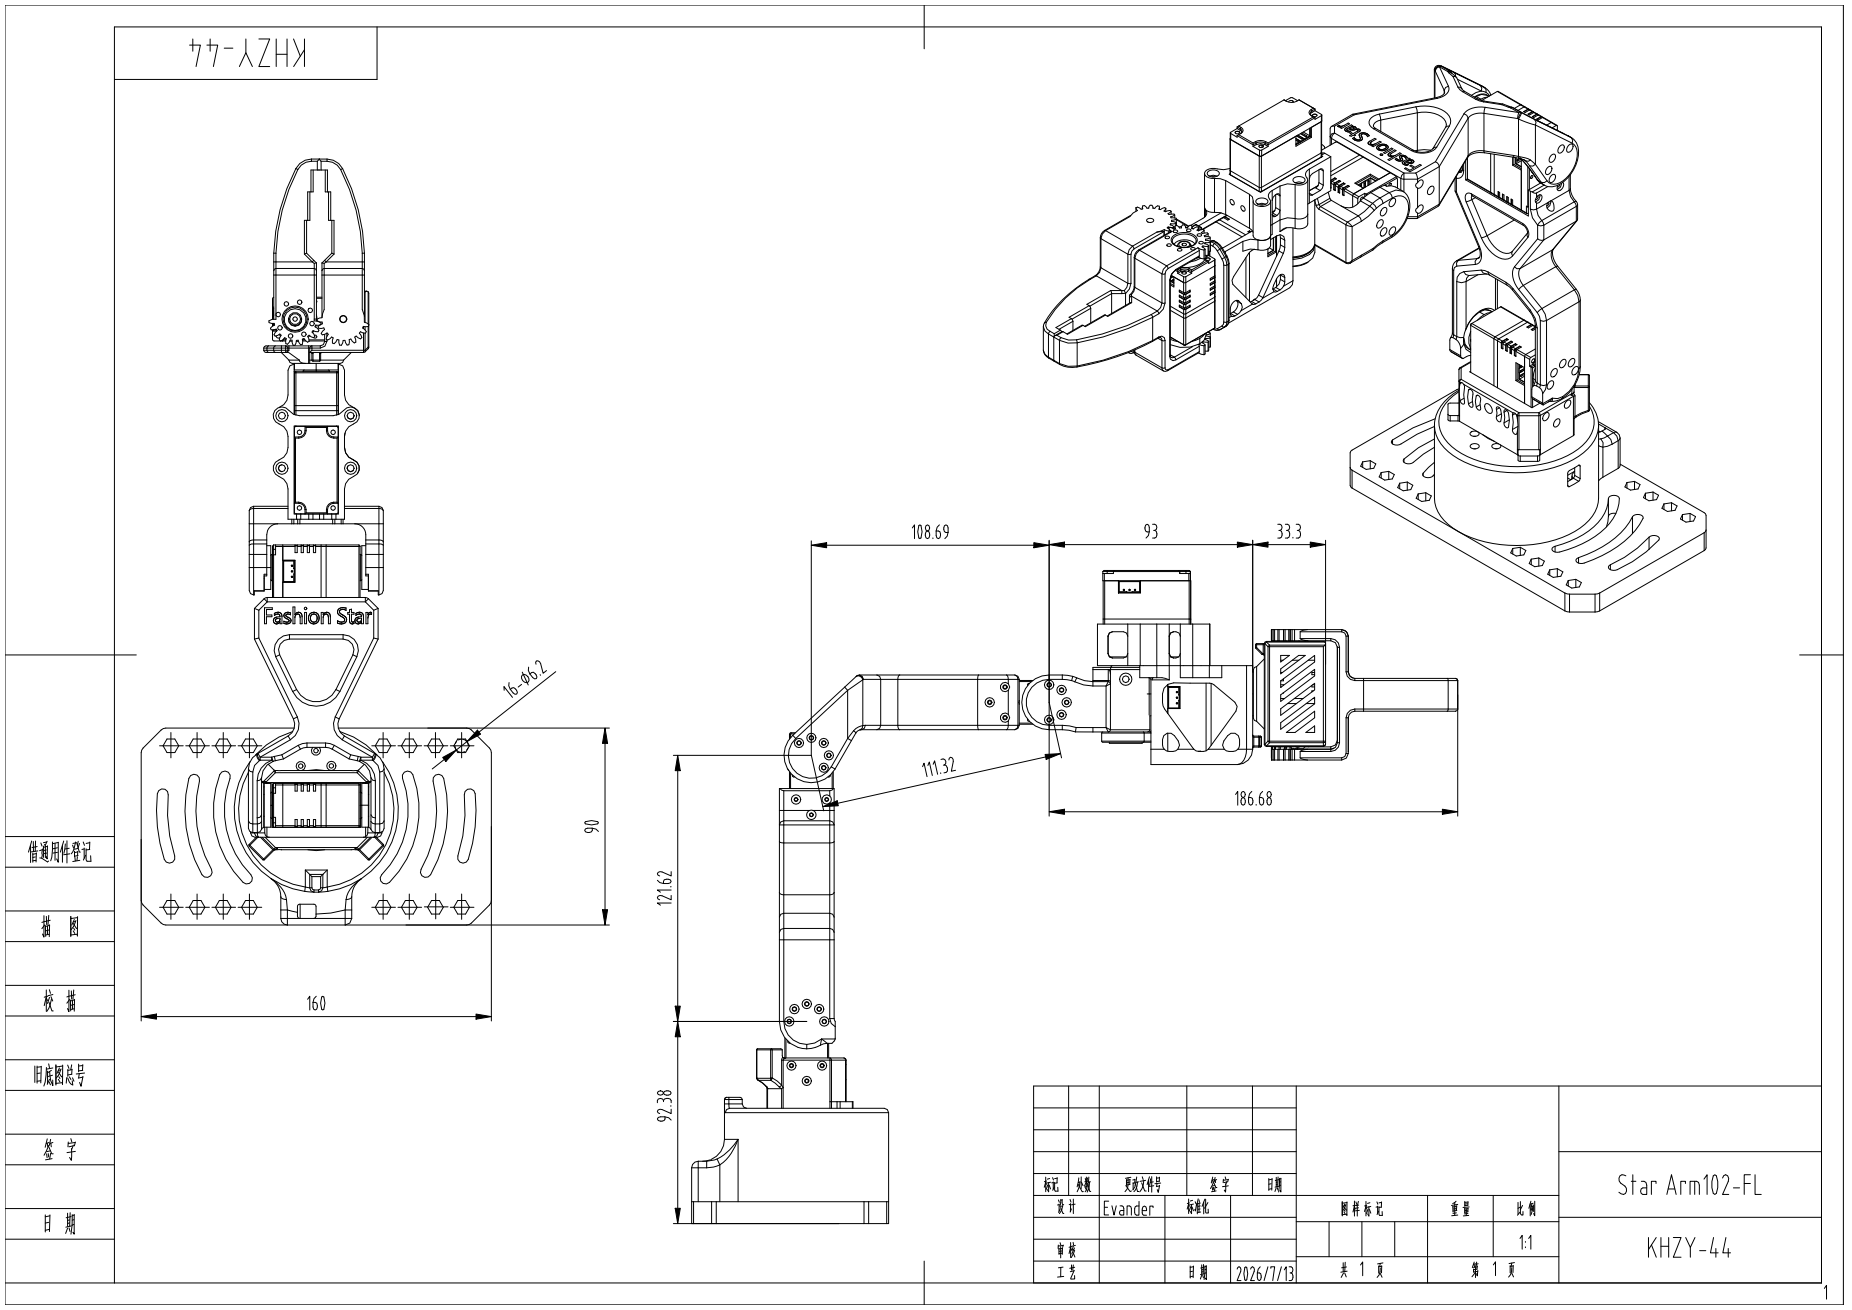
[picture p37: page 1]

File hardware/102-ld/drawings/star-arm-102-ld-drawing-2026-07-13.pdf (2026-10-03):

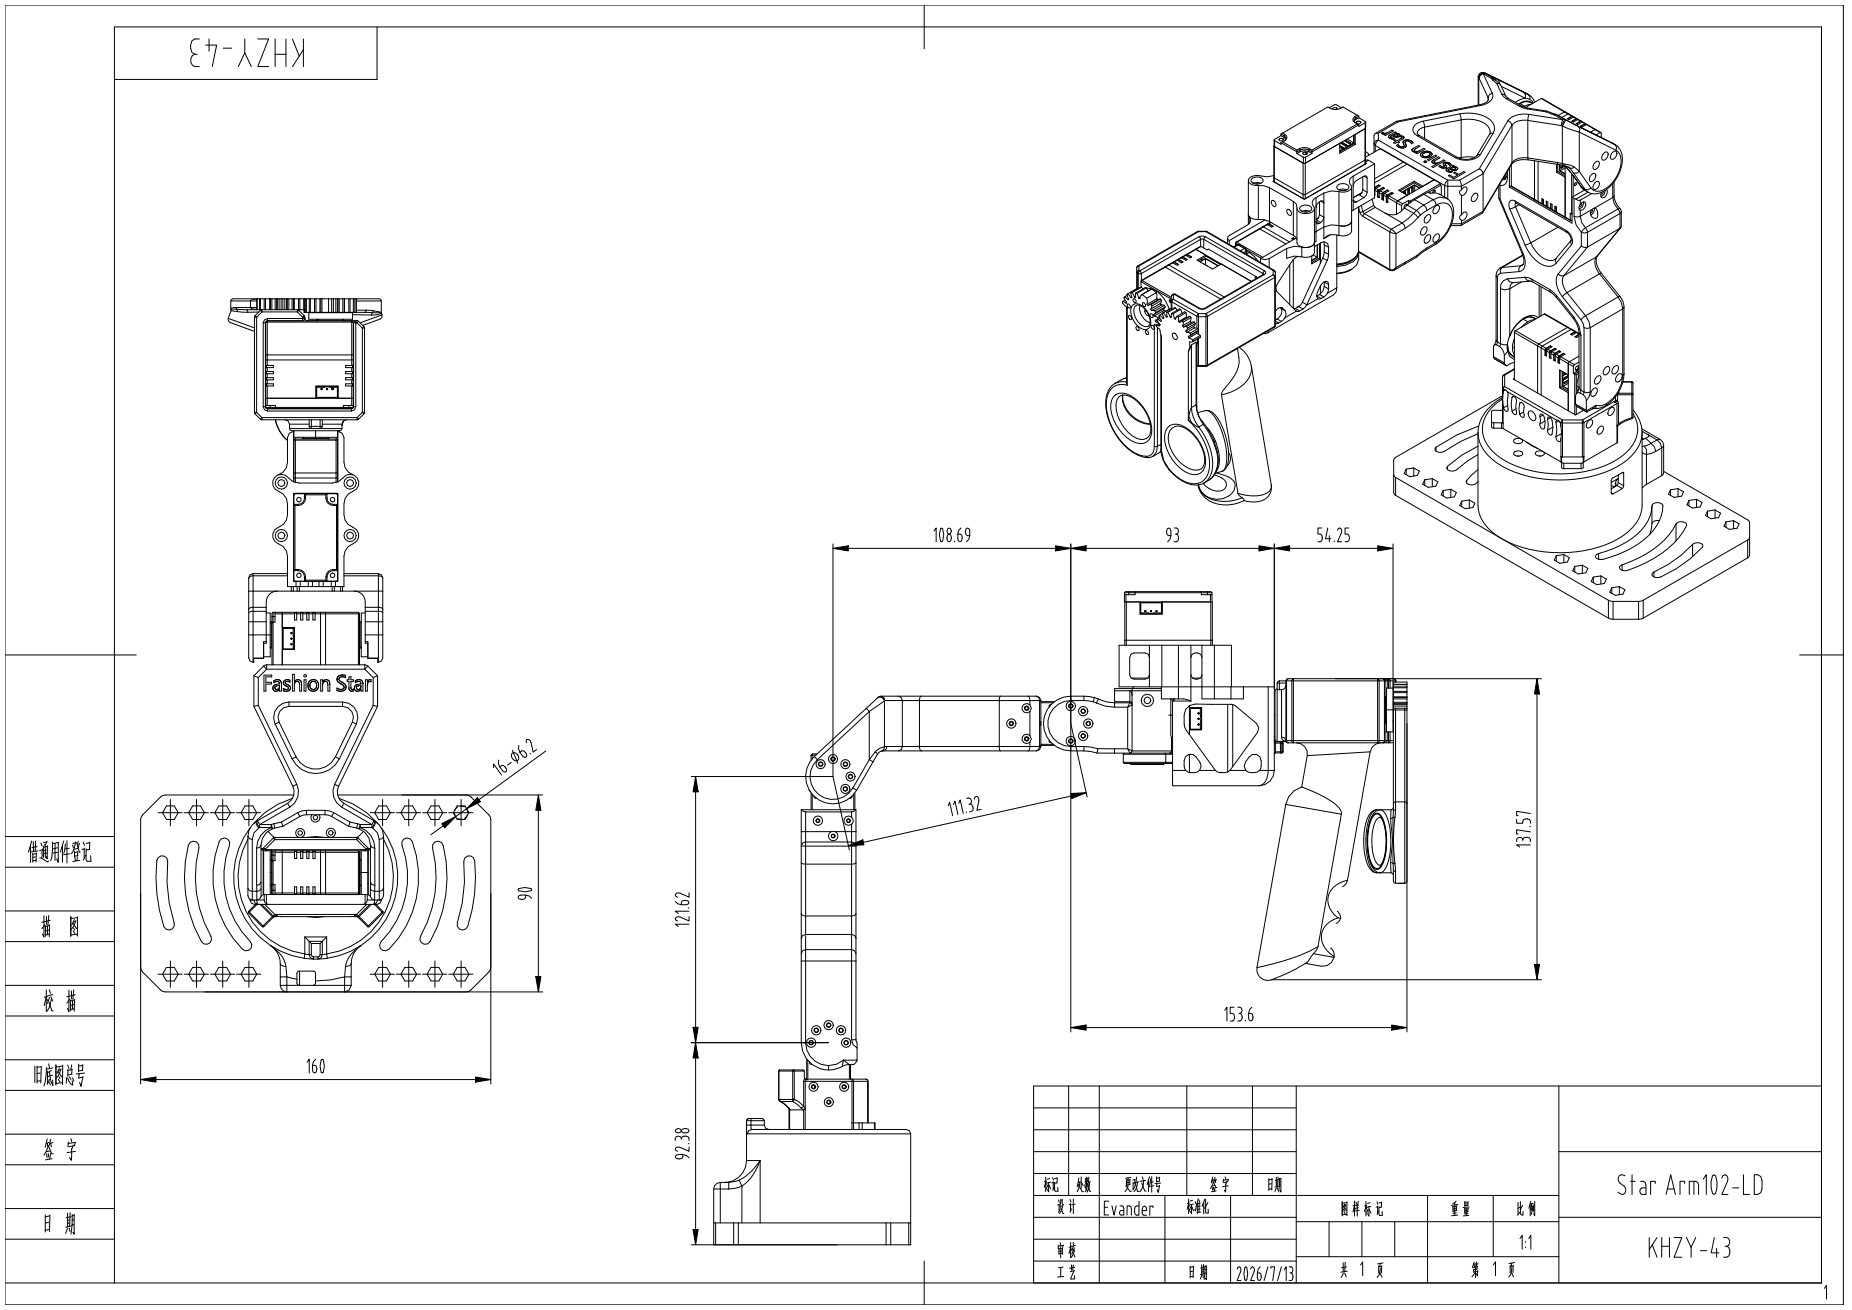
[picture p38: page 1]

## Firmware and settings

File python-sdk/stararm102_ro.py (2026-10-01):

import fashionstar_uart_sdk as uservo
import serial
import time
import struct
import argparse

SERVO_BAUDRATE = 1000000  # 舵机的波特率 / Servo communication baud rate
LEADER_PORT_NAME = "/dev/ttyUSB2"  # leader端口号
FOLLOWER_PORT_NAME_Arr = [
   "/dev/ttyUSB3"
    # "COM33"
    ]  # follower端口号

class Button:
    """
    102_HD 按钮设置
    """
    key_state_0 = 0
    key_state_1 = 180
    key_state_3 = 90
    state = {
        "robot_unlock_state":key_state_0,   # 查询机械臂是否为解锁
        "lock":key_state_1,                 # 控制机械臂为锁定
        "unlock":key_state_3                # 控制机械臂为解锁
    }
    def __init__(self, id=7):
        self.id = id
        self.flag = False   # 记录状态是否发生转变

servo_ids = [0,1,2,3,4,5,6]

def measure_frequency():
    """
    测量循环运行频率（每秒运行次数）
    """
    count = 0
    start_time = time.time()
    
    def get_frequency():
        nonlocal count, start_time
        count += 1
        current_time = time.time()
        elapsed = current_time - start_time
        
        if elapsed >= 1.0:  # 每1秒计算一次频率
            frequency = count / elapsed
            count = 0
            start_time = current_time
            return frequency
        return None
    
    return get_frequency

def main(args):

    # 默认（102LD）
    button_enable = False
    button_id = 7
    filtered_size = 1

    if args.leader_type == "102HD":
        button_enable = True
        button_id = 7
        filtered_size = 1
    elif args.leader_type == "102LD" or args.leader_type is None:
        button_enable = False
        button_id = 7
        filtered_size = 1
    else:
        print(f"Unknown leader type {args.leader_type}; using 102LD defaults")

    if args.button is not None:
        button_enable = args.button
    if args.button_enable:
        button_enable = True
    if args.button_disable:
        button_enable = False

    if args.button_id is not None:
        button_id = args.button_id
    if args.filtered_size is not None:
        filtered_size = args.filtered_size

    # 初始化leader
    leader_uart = serial.Serial(port=args.leader_port,baudrate=SERVO_BAUDRATE,parity=serial.PARITY_NONE,stopbits=1,bytesize=8,timeout=0)
    leader_control = uservo.UartServoManager(leader_uart)
    leader_control.stop_on_control_mode(0xff,0x10,0x00)     # 解锁机械臂
    leader_control.reset_multi_turn_angle(0xff)             # 重置圈数

    if button_enable:
        button_get = leader_control.ping(button_id)
        if button_get==False:
            raise ValueError(f"Button device ID {button_id} did not respond")

    # 初始化follower
    follower_uart_arr = [serial.Serial(port=NAME,baudrate=SERVO_BAUDRATE,parity=serial.PARITY_NONE,stopbits=1,bytesize=8,timeout=0) for NAME in (args.follower_port or FOLLOWER_PORT_NAME_Arr)]
    follower_control_arr = [uservo.UartServoManager(uart) for uart in follower_uart_arr]
    [follower_control_arr[i].stop_on_control_mode(0xff,0x10,0x00) for i in range(len(follower_control_arr))]  # 解锁机械臂
    [follower_control_arr[i].reset_multi_turn_angle(0xff) for i in range(len(follower_control_arr))]          # 重置圈数
    
    button = Button(id=button_id)

    get_frequency = measure_frequency()

    target_angle = [0.0 for i in range(len(servo_ids))]

    target_angle_buffer = []        # 均值滤波缓存
    target_angle_buffer_size = filtered_size   # 滤波数据大小
    
    while True:
        leader_servo_board_ids = servo_ids.copy()
        if button_enable:
            leader_servo_board_ids.append(button.id)
        leader_control.send_sync_servo_monitor(leader_servo_board_ids)
        for id in servo_ids: 
            target_angle[id] = leader_control.servos[id].angle_monitor
        target_angle[-1] = max(0,min(target_angle[-1]*1.5,90))  # 防止角度过大

        # 均值滤波
        target_angle_buffer.append(target_angle.copy())
        if len(target_angle_buffer) > target_angle_buffer_size:
            target_angle_buffer.pop(0)
        filtered_angle = [sum(col) / len(col) for col in zip(*target_angle_buffer)]

        filtered_angle[-1] = target_angle[-1]   # 末端不参与滤波

        if button_enable:
            if(leader_control.servos[button.id].angle_monitor == button.state["lock"]):
                if(not button.flag):
                    for i in range(len(servo_ids)-1):
                        leader_control.stop_on_control_mode(servo_ids[i],0x11,0x00)
                    button.flag = True
            else:
                if(button.flag):
                    leader_control.stop_on_control_mode(0xff,0x10,0x00)
                    button.flag = False

        command_data_list = [struct.pack("<BlLHHH", i, int(filtered_angle[i]*10), 100, 50, 50, 0) for i in servo_ids]

        for i in range(len(follower_control_arr)):
            follower_control_arr[i].send_sync_multiturnanglebyinterval(14,7, command_data_list)
        time.sleep(0.001)

        freq = get_frequency()
        if freq is not None:
            print(f"Loop frequency: {freq:.2f} Hz")


def positive_int(value):
    number = int(value)
    if number < 1:
        raise argparse.ArgumentTypeError("must be a positive integer")
    return number


def parse_bool(value):
    if value.lower() not in ("true", "false"):
        raise argparse.ArgumentTypeError("use true or false")
    return value.lower() == "true"


def build_parser():
    parser = argparse.ArgumentParser(description="Direct Star Arm 102 leader-to-FL teleoperation")
    parser.add_argument("--leader-port", default=LEADER_PORT_NAME,
                        help="leader serial port (default: %(default)s)")
    parser.add_argument("--follower-port", action="append",
                        help="FL serial port; repeat for multiple followers (default: /dev/ttyUSB3)")
    parser.add_argument("--leader_type", "--leader-type", choices=("102LD", "102HD"), default="102LD",
                        help="leader model (default: %(default)s)")
    button_group = parser.add_mutually_exclusive_group()
    button_group.add_argument("--button_enable", action="store_true", help="enable the HD button board")
    button_group.add_argument("--button_disable", action="store_true", help="disable the button board")
    button_group.add_argument("--button", type=parse_bool, default=None, help="button override: true or false")
    parser.add_argument("--button_id", type=int, choices=range(7, 254), default=None,
                        metavar="ID", help="button ID, 7–253; joint IDs 0–6 are reserved")
    parser.add_argument("--filtered_size", type=positive_int, default=None,
                        help="moving-average window, >=1 (default: 1)")
    return parser


if __name__ == "__main__":
    parser = build_parser()
    args = parser.parse_args()
    follower_ports = args.follower_port or FOLLOWER_PORT_NAME_Arr
    if args.leader_port in follower_ports or len(set(follower_ports)) != len(follower_ports):
        parser.error("leader and follower ports must be distinct; do not repeat a follower port")
    main(args)

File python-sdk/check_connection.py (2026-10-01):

"""Check servo responses without changing torque, origin, or target position."""

import argparse
import sys

import fashionstar_uart_sdk as uservo
import serial


def probe(bus, ids):
    """Return missing IDs. Only the SDK ping operation is used."""
    missing = []
    for servo_id in ids:
        online = bus.ping(servo_id)
        print(f"ID {servo_id}: {'OK' if online else 'NO RESPONSE'}")
        if not online:
            missing.append(servo_id)
    return missing


def main(argv=None):
    parser = argparse.ArgumentParser(description=__doc__)
    parser.add_argument("--port", required=True, help="serial port for one arm")
    parser.add_argument("--baudrate", type=int, default=1000000)
    parser.add_argument("--ids", type=int, nargs="+", default=list(range(7)),
                        help="IDs to ping (default: 0 1 2 3 4 5 6)")
    args = parser.parse_args(argv)
    if args.baudrate <= 0 or any(not 0 <= i <= 253 for i in args.ids):
        parser.error("use a positive baud rate and device IDs from 0 to 253")
    try:
        with serial.Serial(args.port, baudrate=args.baudrate, timeout=0) as uart:
            missing = probe(uservo.UartServoManager(uart), args.ids)
    except (serial.SerialException, OSError) as exc:
        print(f"Connection error: {exc}", file=sys.stderr)
        return 2
    if missing:
        print("Check power, port, baud rate, and wiring before commanding motion.", file=sys.stderr)
        return 1
    print("All requested IDs responded. No motion, torque, or origin commands were sent.")
    return 0


if __name__ == "__main__":
    sys.exit(main())

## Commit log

2026-10-01 docs: build English-first Star Arm 102 customer onboarding
    Make the repository a usable entry point for overseas customers with a
    6+1 DOF / LeRobot homepage, capability and language badges, visible official
    website/store links, and a prominent pretrained ACT demo.
    Add English setup, wiring, compatibility, troubleshooting, Python, LeRobot,
    ACT inference, ROS 2, and hardware navigation. Preserve Chinese supplements
    and existing package paths and release URLs. Separate the two LeRobot plugin
    generations and document regular installation for CLI device discovery.
    Add explicit Python serial-port arguments, a ping-only connection check,
    issue forms, documentation checks, and hardware-free entry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
    [check_connection.py, stararm102_ro.py]
2026-10-01 docs: show side-view workspace image in homepage ACT demo
    Replace the homepage's front-view ACT preview with the requested
    setup-side.jpg image and update its descriptive alt text. Preserve the
    video link and image width.
    Validation: inspected the existing image, checked Markdown local links,
    and reviewed the staged diff and whitespace.
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2026-10-03 docs: organize hardware resources and cross-brand customer entry points
    Standardize resource paths with lowercase and hyphens and separate LD, HD,
    and FL hardware indexes. Import reviewed handoff reference assets with
    hash inventories, availability tables, and unresolved version notes. Move
    the shared robot description under hardware and update ROS resource paths.
    Add Wiki-linked tool navigation and a 1920x1080 desktop interface preview.
    Move documentation checks to scripts. Add Galaxea A1, Lumos Touch, YAM,
    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
    [base-link.stl, base_link.STL, bom-102-fl-handoff-08-24.xlsx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]
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2026-10-04 docs: refine bilingual product highlights and pairing gallery
    Streamline homepage navigation, highlight open hardware, Pieper geometry and ROS teaching/force feedback, and clarify the virtual-follower onboarding path. Emphasize assembled and DIY purchase options and expand the hardware directory map.
    Replace cross-brand status rows with linked product images and align reBot documentation with upstream DM/RS coverage. Keep English and Chinese homepages synchronized.
    Validation: check_docs.py (103 files, zero errors), check_readme_sync.py (8 pairs, zero structural errors), manual bilingual review, and git diff --check. Previewed the gallery locally; no new hardware bench validation.
2026-10-04 docs: add assembly videos and shared leader STEP downloads
    Add bilingual LD, HD and FL assembly video entries using YouTube thumbnails. Explain the HD purple coreless bus servo substitution and retain pending coverage notes. Update hardware indexes and resou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
    Add the September 27 FL assembly export while retaining the July reference. Rename the existing LD export to a shared LD/HD filename and provide the identical model in both directories.
    Validation: 106 Markdown files and 11 bilingual pairs checked successfully, manual bilingual review, Markdown whitespace checks, and byte-for-byte comparison of staged STEP files against supplied sou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
    [star-arm-102-fl-export-2026-09-27.step, star-arm-102-ld-hd-assembly-export-2026-07-21.step]
2026-10-04 docs: add model specifications and simplify hardware navigation
    Add synchronized LD, HD, and FL specification tables to the English and Chinese homepages and hardware indexes, including revised power ratings and FL repeatability. Add store product photos to the purchase table.
    Replace redundant hardware datasheet placeholders and download summaries with model entry links, specifications, directory structure, and resource status. Point the homepage Hardware Resources entry to the hardware index.
    Validation: check_docs.py and check_readme_sync.py passed; git diff --check passed. Reviewed bilingual content and local table previews. Operating temperature retains the existing 0-40 C specificati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
2026-10-04 docs: streamline 102-LD hardware resources and inline assembly BOM
    Present 28 numbered assembly items with 11 source images, material descriptions, and print-setting notes in synchronized English and Chinese READMEs. Add a directory/status table and Support Hub link.
    Remove LD internal BOM workbooks, unversioned archive guides, and README files from STEP/printing data directories. Update directory trees, import records, and customer-focused documentation rules; k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
    Validation: check_docs.py, check_readme_sync.py, staged whitespace check, and BOM numbering/image-count checks passed. Local previews reviewed; physical print and hardware validation remain pe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
    [bom-102-ld-handoff-09-10.xlsx, bom-102-ld-kit-handoff-09-10.xlsx, bom-102-ld.xlsx]
2026-10-04 docs: simplify LD downloads and add shared LD/HD URDF archive
    Align LD STEP parts with the 11 printed BOM items, use plain-text BOM names, flatten drawings to one PDF/DWG pair, and simplify assembly navigation. Replace LD/HD robot-description placeholders with identical original URDF ZIP archives and update bilingual resource indexes and links.
    Validation: documentation links, bilingual structure, whitespace, BOM/file-name matching, and archive integrity checks passed. The supplied archive remains ROS 1; RViz configuration, joint limits, and runtime validation are still pending.
    [camera.step, first-person-camera-mount-base.step, first-person-camera-mount-top-cover.step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]
2026-10-04 feat(hardware): add individual 3MF projects for all 11 LD parts
    Split the combined LD project into BOM-named part downloads while preserving mesh data, global settings, colors, and local modifiers. Retain the original combined project and synchronize English and 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
    Validation: all 11 projects passed Bambu Studio slicing without warnings; filenames match STEP/BOM names, source project is unchanged, and documentation/link/sync checks passed. Physical printing rem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
    [star-arm-102-base-bottom.3mf, star-arm-102-base-top.3mf, star-arm-102-finger-ring-left.3mf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]
2026-10-04 feat(hardware): align HD and FL resources with LD layout
    Standardize title-first parent, language and section navigation across directory READMEs. Add synchronized English/Chinese HD and FL resource pages with 31-item and 29-item illustrated BOMs, and remove redundant data-directory guides and internal BOM workbooks.
    Add 13 HD and 11 FL individual 3MF projects with BOM-aligned names; rename combined LD/HD/FL projects and flatten FL drawings. Preserve the FL link1 BOM versus 3MF print-setting discrepancy and mark missing resources explicitly.
    Validation: local documentation links, bilingual README structure and whitespace checks passed. All 24 new individual 3MF projects passed Bambu Studio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
    [bom-102-fl-handoff-08-24.xlsx, bom-102-hd-handoff-09-10.xlsx, camera.step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]
2026-10-05 docs: add accessory CAD resources and bilingual BOMs
    Add camera-module and flexible-gripper directories with supplied STEP parts, a gripper assembly, and bilingual resource indexes and BOMs. Mark unconfirmed materials and quantities explicitly, and lin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
    Add a six-image HD product gallery and move servo items to the start of LD, HD, and FL BOMs without changing item data.
    Validation: documentation links and bilingual structure checks pass; BOM preservation and STEP filename matching checks pass. Original STEP export formatting is retained.
    [dual-shaft-flexible-gripper-body.step, dual-shaft-servo-flexible-gripper-assembly.step, first-person-camera-base-snap-fit.step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]
2026-10-05 docs: rename arm hardware directories and refresh product galleries
    Use star-arm-102-ld, star-arm-102-hd, and star-arm-102-fl directory names and update repository links and trees. Add six-image LD and FL galleries including DIY kits; restore the HD kit image and rem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
    Validation: documentation link and bilingual structure checks passed. Verified 127 resource files remained byte-identical after renaming; all 18 gallery image URLs returned HTTP 200.
    [hd-button-base.3mf, hd-button-base.step, hd-button-cover.3mf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]
2026-10-05 docs: restore short hardware paths and correct servo BOM models
    Rename hardware directories back to 102-ld, 102-hd, and 102-fl and update links and directory trees while retaining product galleries and resource files.
    Restore HD C028/C029 model suffixes, remove firmware suffixes from FL product names, and swap LD BOM rows 2 and 3. Synchronize English and Chinese pages. Documentation link and bilingual structure checks passed.
    [hd-button-base.3mf, hd-button-base.step, hd-button-cover.3mf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]
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2026-10-08 Update arm CAD models, link3 print files and specifications
    Replace LD/HD and FL assembly exports with the supplied 2026-10-08 files and remove superseded exports. Update the LD/HD link3 STEP and individual 3MF files while retaining BOM-compatible filenames. Combined print projects remain unchanged.
    Correct LD/HD/FL weights to 764g/934g/865g in English and Chinese specifications. Align homepage repository tree descriptions and adapt bilingual annotation checking.
    Validation: 68 Markdown files and 14 bilingual README pairs passed documentation checks; replacement files verified against supplied attachments and new 3MF archive integrity checked.
    [star-arm-102-fl-assembly-export-2026-10-08.step, star-arm-102-fl-export-2026-07-03.step, star-arm-102-fl-export-2026-09-27.step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]
2026-10-09 Update FL link3 resources and organize assembly video guides
    Apply the supplied link3 STEP and individual 3MF to FL, matching the files already provided for LD and HD. Combined print projects remain unchanged; the 3mm STEP filename versus 4mm 3MF source metada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
    Add bilingual FL gripper and camera video placeholders, HD button installation and wiring placeholders, and navigation links from accessory resources.
    Validation: local links in 68 Markdown files and structure of 14 bilingual README pairs passed. Supplied file copies and 3MF archive integrity were verified; geometric equivalence is not validated.
    [star-arm-102-link3.3mf, star-arm-102-link3.step]
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2026-10-09 Update link3 print files and simplify language navigation
    Replace all three individual link3 3MF files with the October 9 source, removing the old 4mm internal naming. Add UC-01 images to all three bilingual BOMs and remove globe icons from language navigation and its documentation rule.
    Validated staged documentation links and bilingual structure, 3MF archive integrity, and exact source hashes. Combined print projects are unchanged; URDF reorganization remains outside this commit.
    [star-arm-102-link3.3mf]
2026-10-09 Separate LD/HD and FL URDF source packages and downloads
    Replace the incorrectly labeled shared archive with the supplied leader handle/finger-ring model and publish the follower gripper model separately. Provide matching source directories and reproducible ZIP downloads under hardware/robot-description, with bilingual links from all three arm pages.
    Normalize ROS package identifiers and remove missing RViz config and unused launch argument references. Preserve mesh bytes, joint definitions and physical parameters; retain and document fixed joint5 in the leader export and unvalidated HD dynamics. Existing ROS 2 resources remain unchanged.
    Validation: source ZIP comparisons, 18 mesh byte ch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
    [base_link.STL, link1.STL, link2.STL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]
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2026-10-11 Separate DIY assembly from getting started and unify documentation navigation
    Rewrite the English getting-started guide and add its Chinese counterpart. Centralize LD, HD and FL assembly guides under hardware/diy-assembly, update resource links and directory trees, and replace page-navigation labels with Contents. Preserve Chinese reading destinations where translations exist and update bilingual link normalization. Add a centered AXK2035+2AS image and 20 x 35 x 4 mm specifications to all three BOMs.
    Validation: local links checked across 76 Markdown files; 18 bilingual README pairs passed structural checks. Moved image contents verified unchanged and new assembly preview pages returned HTT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
2026-10-12 Correct power specifications and clarify hardware documentation
    Align LD, HD and FL power specifications to 12 V / 3 A, 5 A and 10 A across the English and Chinese specification tables and hardware setup guide. Clarify CAD (STEP), URDF and printing resource links and remove duplicate numbering from getting-started contents.
    Validation: check_docs.py passed for 76 Markdown files; check_readme_sync.py passed for 18 bilingual README pairs; git diff --check passed.
